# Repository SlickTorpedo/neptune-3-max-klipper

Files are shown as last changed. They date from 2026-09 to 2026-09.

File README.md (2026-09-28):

# neptune-3-max-klipper

> ### ⚠️ Read this first
>
> **Until this note is removed, most of the writing in this repo, including this README and the docs
> alongside it, is Claude's, not a record of a finished build.** It started as a plan drafted
> alongside the work.
>
> Since 2026-09-26, part of it has been **verified on the real machine**: the CAN bus, the toolhead
> board, the Eddy probe, homing, gantry levelling, heater tuning, the extruder and the start/end macros. Those parts are ticked below,
> and the measurements are in [`docs/can-bringup.md`](docs/can-bringup.md). Everything else is still
> plan. The first print is running as of 2026-09-27; nothing has been judged yet.
>
> If you found this repo looking to do the same conversion yourself: **don't follow it blindly yet.**
> Come back when this note is gone. That's the signal the build is done and the docs describe reality.

Gutting an Elegoo Neptune 3 Max and rebuilding it as a real printer: Klipper on a BTT Octopus v1.1,
an SB2209 CAN toolhead on a single umbilical, and a Stealthburner + CW2 carrying an X1C hotend,
probed by a BTT Eddy Duo running [eddy-ng](https://github.com/vvuk/eddy-ng).
The frame, the gantry and the 420 × 420 × 500 build volume stay. Almost nothing else does.

This repo is the config, the wiring notes, and the build log for that conversion.

> **Status (2026-09-27): first print running.** Electronics up, motion and probing calibrated.
> All three MCUs (Octopus, SB2209, Eddy Duo) are running Klipper. Z homes on the Eddy, `Z_TILT_ADJUST`
> levels the gantry to about 0.001 mm, and both heaters are PID-tuned.
> Done 2026-09-27: silicone spacers + tram (mesh 0.72 mm, gantry bow only), new Y motor, extruder verified
> (100 mm = 100 mm), PRINT_START / PRINT_END with KAMP, and an OrcaSlicer profile. **Next:** judge the first print, input shaping.

<p align="center">
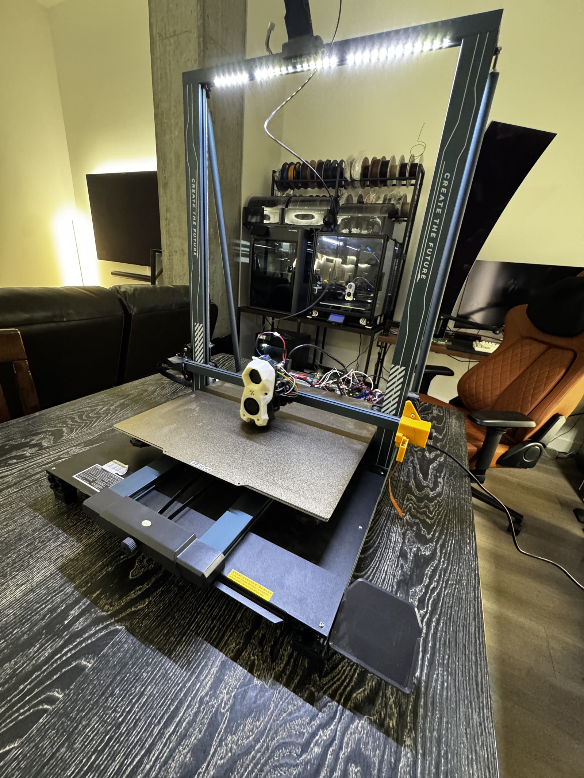
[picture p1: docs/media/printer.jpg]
The converted Neptune 3 Max
  
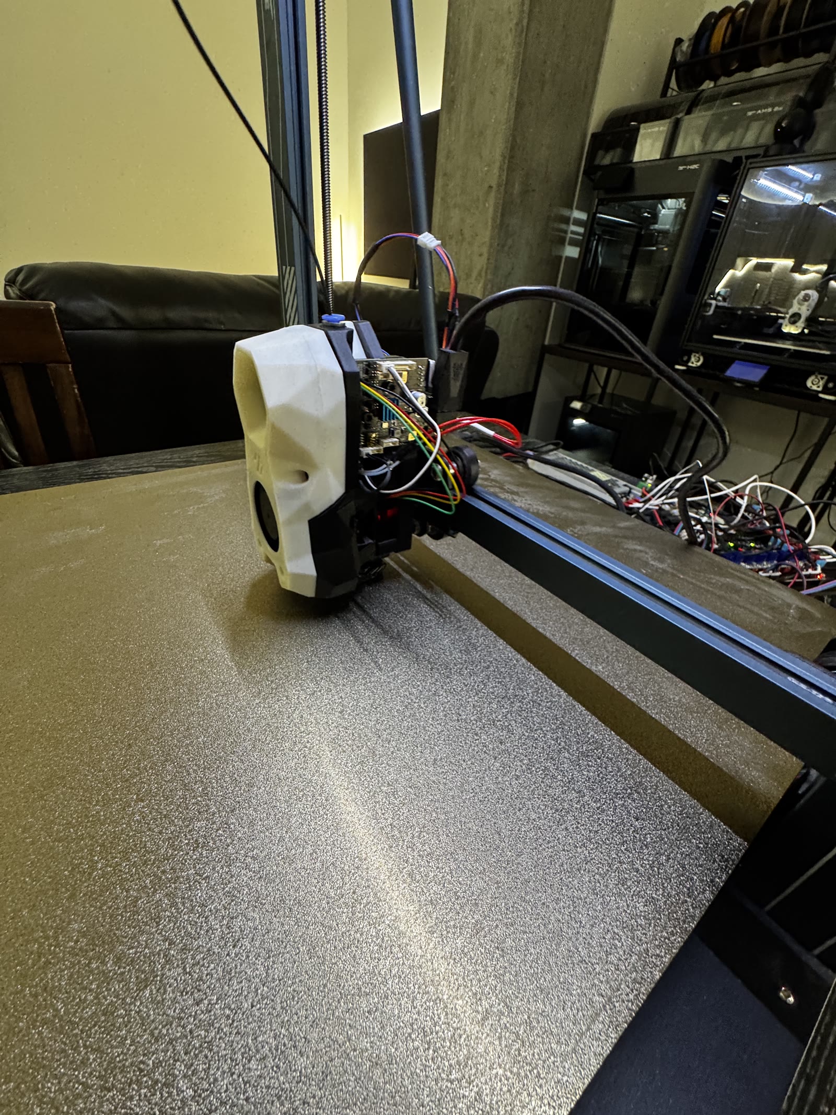
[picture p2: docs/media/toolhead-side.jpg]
Stealthburner toolhead with the SB2209 on the back
  
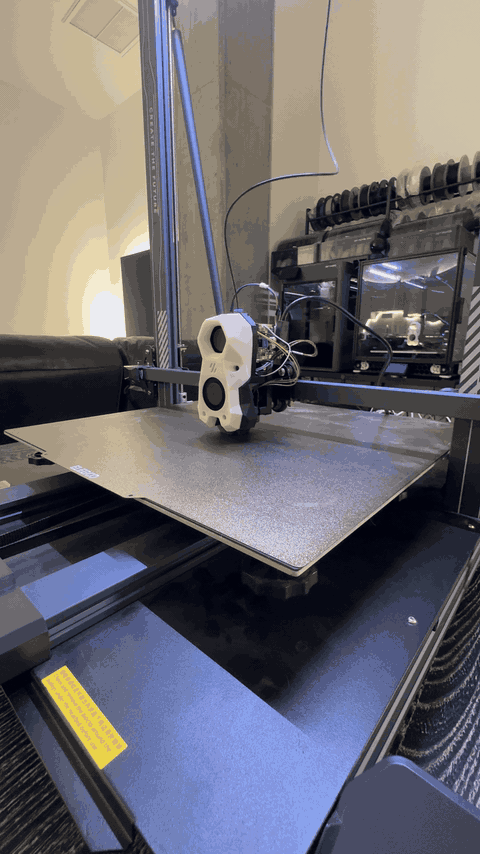
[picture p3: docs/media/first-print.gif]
First print (Voron cube), 2026-09-27
  
</p>

<p align="center"><sub>
  <b>Left:</b> the whole machine. <b>Middle:</b> Stealthburner + CW2 with the SB2209 on the back; the Eddy Duo is sealed inside.
  <b>Right:</b> first print, a Voron cube, 2026-09-27 (<a href="docs/media/first-print.mp4">MP4</a>).
</sub></p>

---

## Why

The Neptune 3 Max is a big printer sold at a small price, and every corner that got cut shows up
the moment you ask it for anything. The stock story:

- A closed-ish Marlin build on an Elegoo/MKS board with no meaningful tuning surface: no input
  shaping worth the name, no pressure advance you can iterate on, no real macro system.
- A PTFE-lined hotend that caps out around 260 °C and clogs if you look at it funny, on a
  proprietary extruder assembly.
- A 420 × 420 DC-powered bed that takes forever to come up to temperature and never gets flat.
- Stock ABL that samples too few points for a bed this size and fights a gantry that sags.
- Wiring that makes the toolhead a bird's nest of loose conductors dragging across the gantry.

The frame, the Z height and the sheer footprint are the parts worth keeping. Everything that
touches filament or decides where the nozzle goes gets replaced.

---

## The plan, in one table

| Subsystem | Stock | Target | State |
|---|---|---|---|
| Firmware | Marlin (Elegoo build) | **Klipper** + Moonraker + Mainsail | ✅ running |
| Host | — | **Raspberry Pi** | ✅ |
| Mainboard | Elegoo/MKS ZNP Robin Nano | **BTT Octopus v1.1** (STM32F446), plain USB Klipper | ✅ |
| Stepper drivers | Onboard, fixed | **TMC2209** UART | ✅ |
| Toolhead wiring | Loose harness to mainboard | **CAN bus**, single umbilical, 1 Mbit | ✅ |
| CAN adapter | — | **BTT U2C v2.1** | ✅ |
| Toolhead board | — | **BTT SB2209** (STM32G0B1), Katapult + Klipper | ✅ |
| Extruder | Elegoo direct drive | **Stealthburner + CW2** (Filamatrix) | fitted; direction/rotation not checked |
| Hotend | PTFE-lined, ~260 °C max | **X1C / Bambu-style** ceramic heater, Generic 3950 | ✅ PID-tuned |
| Probe | Elegoo ABL sensor | **BTT Eddy Duo** in CAN mode (its own node) + **eddy-ng** | ✅ calibrated, tap works |
| Z | Dual screws, belt-synced | **Independent dual Z** + `z_tilt` | ✅ |
| Bed leveling | Knobs + mesh | `z_tilt` + eddy-ng tap + Eddy rapid-scan adaptive mesh | ✅ mesh / 🔜 tram |
| Heated bed | Stock DC bed | Stock DC bed via an **external DC MOSFET** on Octopus HE0 | ✅ PID-tuned |
| Part cooling | Single stock blower | Stealthburner part fan + 4010 hotend fan | ✅ both verified |
| LEDs / feedback | Stock LCD | Stealthburner WS2812B LEDs | not fitted (config ready, commented out) |

---

## Bill of materials

`[x]` = in hand, `[ ]` = not sourced yet.

### Electronics
- [x] BTT Octopus v1.1 + TMC2209 drivers
- [x] BTT SB2209 CAN toolhead board
- [x] BTT U2C v2.1 USB-to-CAN adapter (arrived early, 2026-09-26)
- [x] Raspberry Pi host
- [x] Umbilical: the SB2209 kit cable (24 V, GND, CANH, CANL) to the U2C; the U2C's 24 V/GND terminals are fed from the PSU
- [x] Second Z motor for independent Z
- [x] 24 V PSU. Still worth **checking its rating against the new total load**.
- [x] DC MOSFET module for the bed, driven from Octopus HE0
- [x] Ferrules, heat-shrink, crimp tooling

The CAN bus runs from the U2C to the toolhead. It's terminated at exactly two points: the **U2C**
and the **Eddy Duo**, which has its own built-in terminator. The SB2209's 120R jumper is **off**:
with it on, the bus measured 41 Ω; with it off, 60 Ω. Bring-up steps, jumpers, UUIDs and every
measurement are in [`docs/can-bringup.md`](docs/can-bringup.md).

### Toolhead
- [x] Stealthburner shroud + CW2 kit (Filamatrix, single filament switch on the SB2209, verified)
- [x] X1C-style hotend
- [x] Part cooling blower + 4010 hotend fan
- [x] Stealthburner LED PCB / WS2812B (not fitted yet)
- [ ] Hotend→CW2 adapter mount (the same problem already solved on the Voron; reuse that solution)
- [x] **BTT Eddy Duo** scanning probe (CAN mode, sealed in the Stealthburner; flashed over CAN without opening it)

Still open for the X1C hotend: confirm the **ceramic heater's wattage against what the SB2209's
heater output can safely supply**. The thermistor is settled: `Generic 3950` reads correctly at
room temperature and PID-tuned cleanly at 250 °C.

### Electronics layout (temporary)

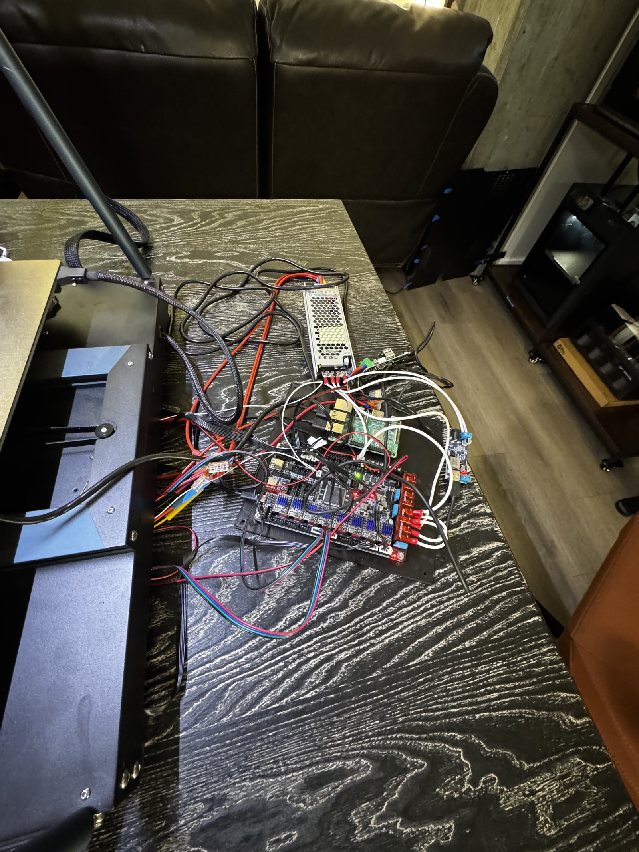
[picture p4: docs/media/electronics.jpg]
Bench layout of the electronics


For now the Octopus, Pi, U2C, PSU and the bed's DC MOSFET module sit loose next to the printer while things are still changing.
A proper holder that mounts them under the printer is planned once the layout settles.

<br clear="right">

### Mechanical
- [x] **Carriage adapter.** Ben Ford's Neptune 3/4 Stealthburner plate (Printables 1185615), fitted.
      The Eddy coil sits 27.33 mm behind the nozzle, and the bottom of its case is about 2.0 mm
      above the nozzle tip.
- [x] Hardware to de-sync the Z screws and mount the second motor
- [x] Belts / tensioners
- [x] Umbilical anchor points
- [x] 18 mm silicone bed spacers (4 mm ID) to replace the bed springs; 7 needed (M3 screws)

---

## Repo layout

```
config/            Klipper configs (the Pi's ~/printer_data/config mirrors this)
  printer.cfg        Root config: Octopus, steppers, bed heater, and the SAVE_CONFIG block
  hardware/
    sb2209.cfg       Toolhead MCU, extruder, hotend, fans, ADXL, Filamatrix sensor
    eddy.cfg         Eddy Duo MCU + probe_eddy_ng
    eddy_homing.cfg  homing_override: Z always homes with the coil over the bed centre
    z_tilt.cfg       Dual-Z levelling (stepper_z is the RIGHT screw)
    screws_tilt.cfg  Bed tramming over the 6 outer bed screws
    bed_mesh.cfg     21×21 mesh, scanned at 2 mm
  macros/print.cfg   PRINT_START / PRINT_END (eddy-ng tap + native adaptive mesh + KAMP purge)
  KAMP_Settings.cfg  KAMP (LINE_PURGE, SMART_PARK). On the Pi, config/KAMP is a symlink to
                     ~/Klipper-Adaptive-Meshing-Purging/Configuration, and mainsail.cfg comes from mainsail-config
docs/
  can-bringup.md     The bring-up log: hardware IDs, jumpers, UUIDs, every calibration result
firmware/          Katapult/Klipper .config per MCU (Octopus, SB2209, Eddy Duo) + where each value came from
stl/               Printable parts, sorted by print colour
  toolhead/          Stealthburner + CW2 (FilamATrix) for the X1C hotend
cad/               Adapter plates and printed brackets specific to this conversion
```

`stl/` is organised so each colour folder can be imported whole and printed in one go. See
[`stl/toolhead/README.md`](stl/toolhead/README.md) for the layout and the variant choices.

**Keeping the Pi and the repo in sync:** `SAVE_CONFIG` writes calibration into `printer.cfg` on
the Pi. Copy it back into `config/` after every save.

---

## Build phases

### Phase 0: Document the stock machine *(before the screwdriver comes out)*
- [ ] Photograph the wiring harness end to end, both ends of every connector
- [ ] Record stock steps/mm, belt pitch, pulley tooth counts, lead-screw pitch
- [ ] Note thermistor types and heater wattage (bed especially, since it gets reused)
- [ ] Record endstop types and wiring polarity (NO/NC)
- [ ] Back up the stock firmware and anything worth remembering from its settings

### Phase 1: Teardown
- [x] Strip the stock toolhead, mainboard, display and harness
- [x] Keep: frame, gantry, rails, motors, bed, PSU
- [x] De-sync the Z screws and fit the second Z motor
- [ ] Inspect rails and lead screws; clean and re-lube

### Phase 2: Electronics bring-up
- [x] U2C on `can0` at 1 Mbit (fixed U2C firmware flashed); Octopus on plain USB Klipper
- [x] Katapult on the SB2209 via USB DFU, then Klipper over CAN; Eddy Duo flashed over CAN through its factory bootloader
- [x] Termination at both ends of the bus and nowhere else (60 Ω)
- [x] Both Z motors move together and in the same direction (positive = up)
- [ ] Extruder direction under a cold/hot extrude test

### Phase 3: Mechanical install
- [x] Mount the Octopus and the Pi, route the umbilical
- [x] Fit the carriage adapter + Stealthburner + X1C hotend
- [ ] Re-tension belts, square the gantry
- [ ] Swap bed springs for silicone spacers, then tram with `SCREWS_TILT_CALCULATE`

### Phase 4: First motion
- [x] X/Y homing on the stock switches
- [x] Z homes on the Eddy (`probe:z_virtual_endstop`, eddy-ng)
- [x] `z_tilt` defined for the real screw positions; `Z_TILT_ADJUST` converges to about 0.001 mm.
      The first attempt diverged because the bench config had the Z motors labelled backwards.
- [x] Probe offsets measured (x 0, y +27.33); Z offset comes from the eddy-ng tap before each print
- [ ] Sanity-check `position_max` for the full 420 × 420 × 500 envelope

### Phase 5: Heat and tune
- [x] PID: hotend (250 °C) and bed (60 °C)
- [x] eddy-ng setup, warm; tap standard deviation 0.001 mm
- [x] Mesh baseline: 21×21 rapid scan, range 0.91 mm (about 0.24 mm gantry bow plus a bed twist, to be trammed out)
- [ ] `verify_heater` / thermal runaway verified by actually provoking it
- [ ] `rotation_distance` calibration for E (XY too)
- [ ] Input shaping (ADXL on the SB2209, responding), pressure advance, flow

### Phase 6: Make it pleasant
- [ ] PRINT_START / PRINT_END: home, heat, Z_TILT, clean nozzle at 150 °C, tap, adaptive mesh, purge
- [ ] Filament runout handling (Filamatrix), pause/resume that doesn't compound errors
- [ ] Stealthburner LEDs (optional)
- [ ] Timelapse, camera, remote monitoring

---

## Open decisions

1. **Bed.** Now the stock DC bed through an external MOSFET. AC bed + SSR is still a real upgrade
   and a real safety project. Deferred, not dismissed.
2. **PSU headroom.** Add up the new load (bed + hotend + steppers + fans + Pi) against the
   supply's rating.
3. **Gantry.** It visibly bows in the middle (about 0.24 mm on the Eddy). The mesh compensates for
   now; the gantry is due to be replaced eventually.
4. **Stock Elegoo runout sensor.** Still wired (Octopus PG10) but not mounted. It pauses nothing and
   isn't used by any macro.
5. **Eddy height.** eddy-ng's ideal is about 1.75 mm from the case bottom to the nozzle tip; this
   mount gives about 2.0. Tap works well as is, so only revisit it if taps get unreliable.

## Known quirks

- **"Failed automated reset of MCU 'eddy'"** after a config change: the Eddy (software CAN on its
  RP2040) sometimes misses Klipper's reset command. Run `FIRMWARE_RESTART` again; it has worked every time.
- **The Pi sometimes comes back as `neptune-2.local`** (mDNS name clash). It returns to
  `neptune.local` on its own later.
- **eddy-ng patches Klipper's source.** Before updating Klipper: `~/eddy-ng/install.sh --uninstall`,
  update, reinstall, then rebuild and reflash the MCUs. See [`firmware/README.md`](firmware/README.md).

---

## Safety

Blunt, because this build touches heaters and possibly mains:

- **Verify the X1C heater's power draw against the SB2209's heater output.** An undersized MOSFET
  on an oversized heater is a fire, not a fault.
- **Mains wiring is not a "figure it out as you go" area.** Earth to every metal case, proper
  connectors, strain relief. If the AC bed happens, it also gets a grounded bed plate, a correctly
  rated SSR with a heatsink, and a thermal fuse.
- **Thermal runaway protection gets tested, not assumed.** Klipper's `verify_heater` only helps
  if the config is right and you've watched it trip.
- **The hotend fan has no speed sensor.** It was once found jammed mid-heat. A stalled hotend fan
  cooks the Stealthburner's printed parts, so look at it after any toolhead work.
- **Never leave the first heat soak unattended.**
- No unattended printing until PID, runaway protection and the first hundred hours are behind it.

---

## References

- Klipper: https://www.klipper3d.org/
- Klipper CAN bus guide: https://www.klipper3d.org/CANBUS.html
- Esoterical's CANBus guide: https://canbus.esoterical.online/
- Moonraker: https://moonraker.readthedocs.io/
- Mainsail: https://docs.mainsail.xyz/
- BTT Octopus v1.1 docs: https://github.com/bigtreetech/BIGTREETECH-OCTOPUS
- BTT SB2209 docs: https://github.com/bigtreetech/EBB
- BTT Eddy: https://github.com/bigtreetech/Eddy
- eddy-ng: https://github.com/vvuk/eddy-ng (wiki: https://github.com/vvuk/eddy-ng/wiki)
- Katapult (CAN bootloader): https://github.com/Arksine/katapult
- Voron Stealthburner: https://github.com/VoronDesign/Voron-Stealthburner
- Neptune 3 Max bed screw positions: https://github.com/TheFeralEngineer/Klipper-for-Elegoo-Neptune-series-3D-Printers

---

## License

TBD.

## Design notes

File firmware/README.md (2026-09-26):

# Firmware build configs

One `.config` per board and per image. Build on the Pi with:

```bash
cd ~/klipper   # or ~/katapult
make clean KCONFIG_CONFIG=<path>/klipper_sb2209.config
make KCONFIG_CONFIG=<path>/klipper_sb2209.config
```

The files were generated with `make olddefconfig` against Klipper `ce7002b` (2026-09-18) and Katapult
`ec59b9b` (2026-03-20). If the Pi's checkouts are newer, run `make menuconfig KCONFIG_CONFIG=...`
once and check that the values below still hold before building.

The CAN adapter is a **BTT U2C v2.1**, so the Octopus is **not** a USB-to-CAN bridge.

| File | Board | Key values | Source |
|---|---|---|---|
| `klipper_octopus_usb.config` | Octopus v1.1, STM32F446ZET6 (chip read off the board 2026-09-25) | 32KiB bootloader, 12 MHz crystal (crystal can reads 12.000), USB on PA11/PA12 | Esoterical guide, Octopus page, F446 screenshots. The bridge config there differs only in the communication interface. |
| `katapult_sb2209.config` | EBB SB2209 CAN v1.0, STM32G0B1 | 8KiB deployer + 8KiB app offset, 8 MHz crystal, CAN on PB0/PB1, 1,000,000, double-reset entry, status LED PA13 | Esoterical guide, "BigTreeTech SB2209 and SB2240" page, Katapult screenshot |
| `klipper_sb2209.config` | same | 8KiB bootloader, 8 MHz crystal, CAN on PB0/PB1, 1,000,000 | same page, Klipper screenshot. 8 MHz crystal (X1) and FDCAN2 on PB0/PB1 are also confirmed in BTT's `BIGTREETECH EBB SB2209 CAN V1.0_SCH.pdf`. |
| `katapult_eddy.config` | Eddy Duo, RP2040 | W25Q080 CLKDIV 2, 16KiB bootloader, CAN RX gpio4 / TX gpio5, 1,000,000, no status LED | Esoterical guide, "BigTreeTech Eddy Duo" page, Katapult screenshot. **Only needed for a USB recovery.** The plan is to use whatever bootloader the Eddy already has. |
| `klipper_eddy.config` | same | 16KiB bootloader, CAN RX gpio4 / TX gpio5, 1,000,000 | same page, Klipper screenshot |

Notes:

- **eddy-ng:** the Pi's `~/klipper` has eddy-ng (1ed056b) installed. That links `src/sensor_ldc1612_ng.c` and
  two klippy extras, and patches `src/Makefile` and `klippy/extras/bed_mesh.py`. The Eddy image **must** be
  built from that patched tree. The SB2209 image was rebuilt from it too. The Octopus keeps its existing firmware: same Klipper commit, and only the Eddy uses the new sensor code.
  Before any Klipper update: `~/eddy-ng/install.sh --uninstall`, `git pull`, `install.sh`, then rebuild and
  reflash all MCUs.

- **Eddy offset:** on the RP2040, Katapult always launches the application at `0x10004000` (fixed in
  `katapult/src/rp2040/Kconfig`, `LAUNCH_APP_ADDRESS`). So any Katapult/CanBoot the Eddy shipped
  with requires the 16KiB bootloader offset, and there's nothing to guess.
- **Eddy I2C bus:** BTT's sample config uses `i2c0f` (i2c0 on GPIO20/21), which doesn't clash with
  the CAN pins (GPIO4/5).
- **CAN bitrate:** every image uses 1,000,000, matching `can0` on the Pi.

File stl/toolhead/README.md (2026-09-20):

# Toolhead STLs

Stealthburner + Clockwork 2 (FilamATrix fork) with a Bambu/X1C-style hotend, sorted by
**print color** rather than by upstream source.

Each colour folder is meant to be imported whole: select the entire folder, drop it on the
plate, set one colour, print. No file-by-file picking, no leftover parts you didn't want.

## Folders

| Folder | Print in | What's in it |
|---|---|---|
| `primary/` | Primary colour | Main structural parts with no filename prefix |
| `accent/` | Accent colour | Everything upstream marked `[a]` |
| `clear/` | Clear / translucent | The LED diffuser — it has to pass light |
| `opaque/` | Opaque, ideally black | LED carrier and diffuser mask — these **block** light; a translucent print here bleeds and ruins the effect |
| `jigs/` | Anything | Assembly tools, not printer parts. Print once, keep in the toolbox |
| `alternates/` | **Don't print** | The roads not taken — see below |

## Quantities

**Every part here is quantity 1.** Nothing needs duplicating.

Voron's own file convention encodes quantity in the filename with an `_x2` / `_x3` / `_x4`
suffix — a part needed in multiples ships pre-named that way. None of the files in this set
carry a suffix, upstream or here, so a single copy of each is correct. If a part ever does
need multiples, it'll show up here as `name_x1.stl`, `name_x2.stl`, `name_x3.stl` so the
whole folder can still be imported in one go.

Filenames are otherwise unchanged from upstream, so they stay traceable to the source repos.

## What's in `alternates/` and why

These are the choose-one variants that lost. They're kept for reference in case a decision
gets revisited — **they are not part of the build as specified.**

| File | Why it's not being printed |
|---|---|
| `main_body_clockwork2_no_switch.stl` | AFC default (relies on buffer ramming instead of a toolhead sensor) |
| `main_body_clockwork2_dual_switch.stl` | Two switches; only one is needed here |
| `cable_cover_pcb.stl` | Pairs with the no-switch body |
| `[a]_knife_holder_olfa.stl` | Olfa blade variant; this build uses a standard razor |
| `razor_safety_cap_olfa.stl` | Same — Olfa variant |
| `chain_anchor_2hole.stl` / `chain_anchor_3hole.stl` | For cable chains. This build runs a CAN umbilical, so there's no chain to anchor |

**Chosen configuration:** single-switch CW2 main body + `cable_cover_pcb_w_sensor`, standard
razor blade, Filametrix cutter included, no cable chain.

## Print settings

Standard Voron guidance applies:

- **ABS or ASA.** These parts sit next to a hotend; PLA will sag and deform.
- 4 perimeters, 5 top/bottom layers, 40% infill
- No supports needed on any part — they're all oriented to print as-is
- The `clear/` diffuser wants a translucent filament; SLA prints of this part are common and
  look better than FDM if that's an option

## Sources

- FilamATrix (CW2 fork with the toolhead cutter) — https://github.com/thunderkeys/FilamATrix
- Voron Stealthburner (stock Stealthburner + CW2 parts) — https://github.com/VoronDesign/Voron-Stealthburner

The upstream READMEs that came with the download are preserved verbatim in `reference/`.

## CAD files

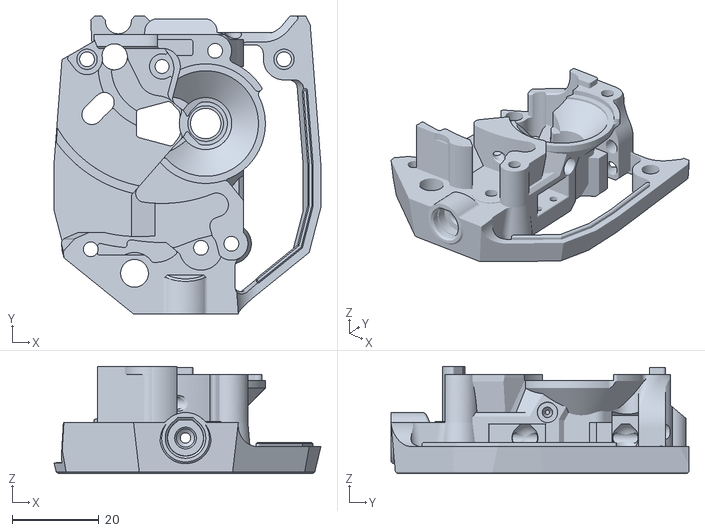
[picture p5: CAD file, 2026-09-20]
stl/toolhead/alternates/main_body_clockwork2_dual_switch.stl
61.5 x 68.7 x 24.7

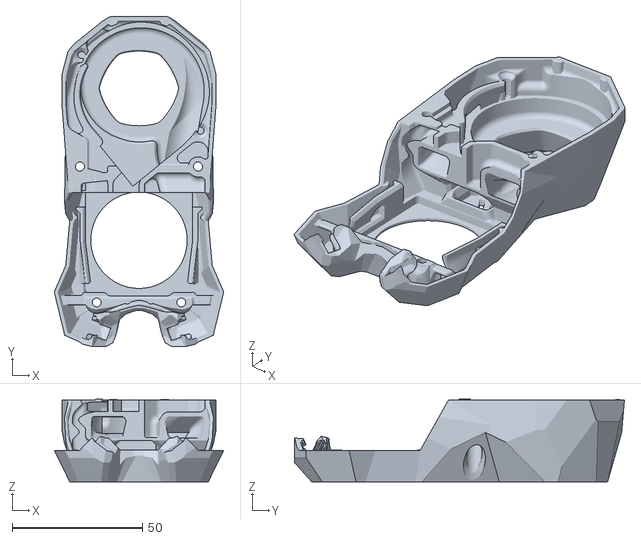
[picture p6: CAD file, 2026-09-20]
stl/toolhead/accent/[a]_stealthburner_main_body.stl
65.1 x 126.8 x 31.8

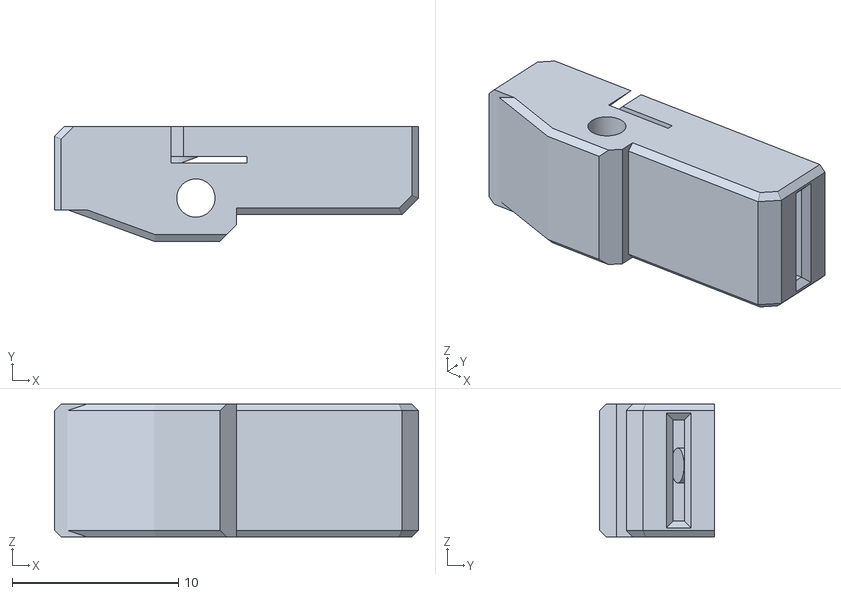
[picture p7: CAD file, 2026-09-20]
stl/toolhead/accent/[a]_knife_holder.stl
21.9 x 6.90 x 8.00

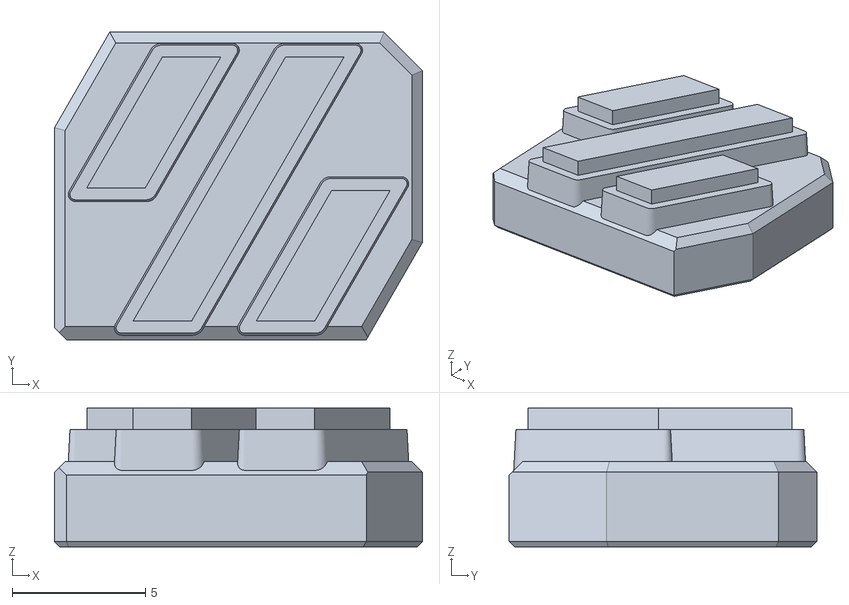
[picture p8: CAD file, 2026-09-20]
stl/toolhead/clear/[c]_stealthburner_LED_diffuser.stl
13.8 x 11.5 x 5.20

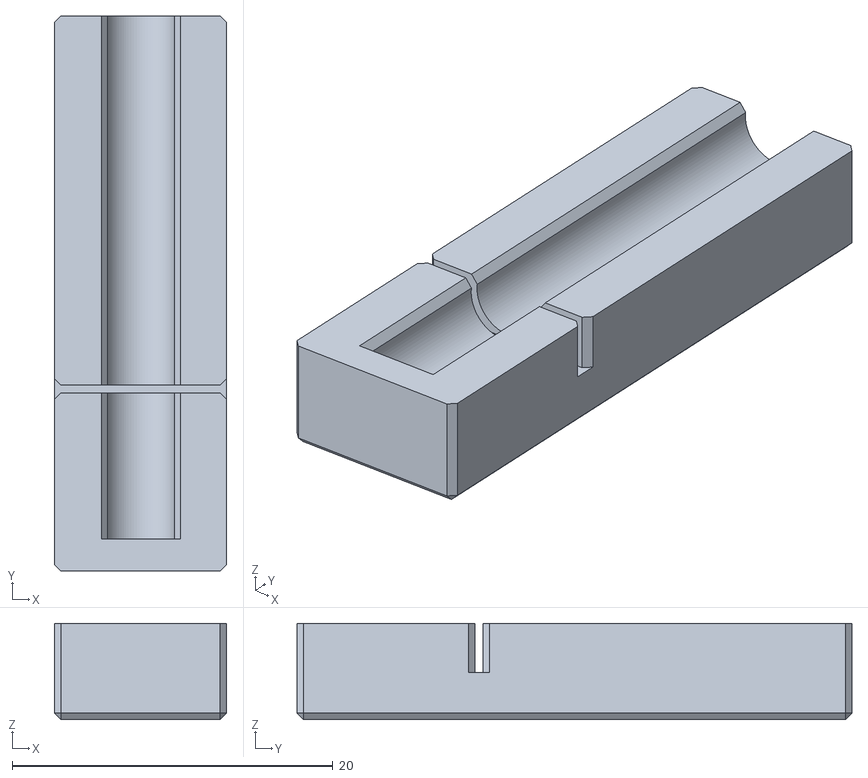
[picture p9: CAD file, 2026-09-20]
stl/toolhead/jigs/bambu_ptfe_jig.stl
10.7 x 34.6 x 6.00

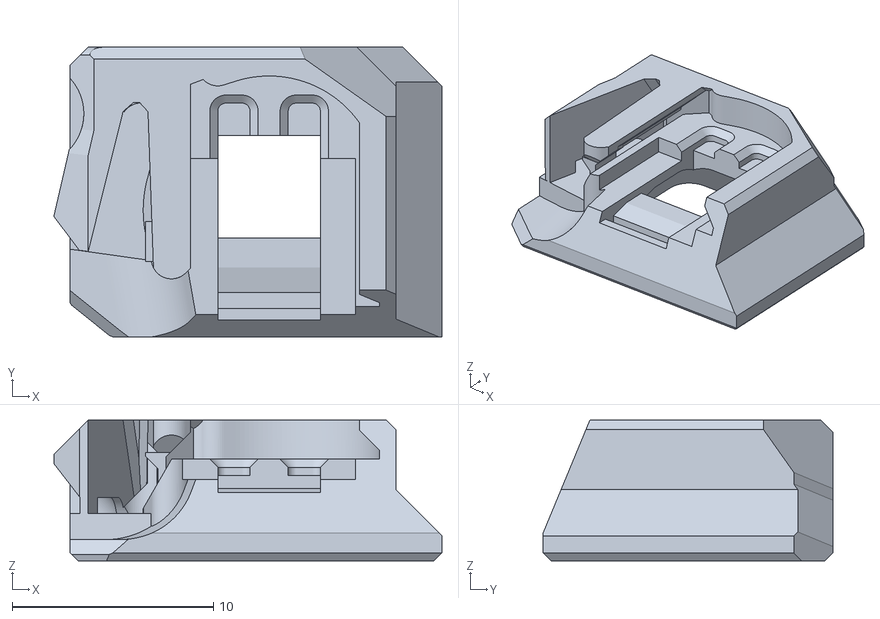
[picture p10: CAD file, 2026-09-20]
stl/toolhead/opaque/[o]_stealthburner_LED_carrier.stl
19.3 x 14.4 x 7.01

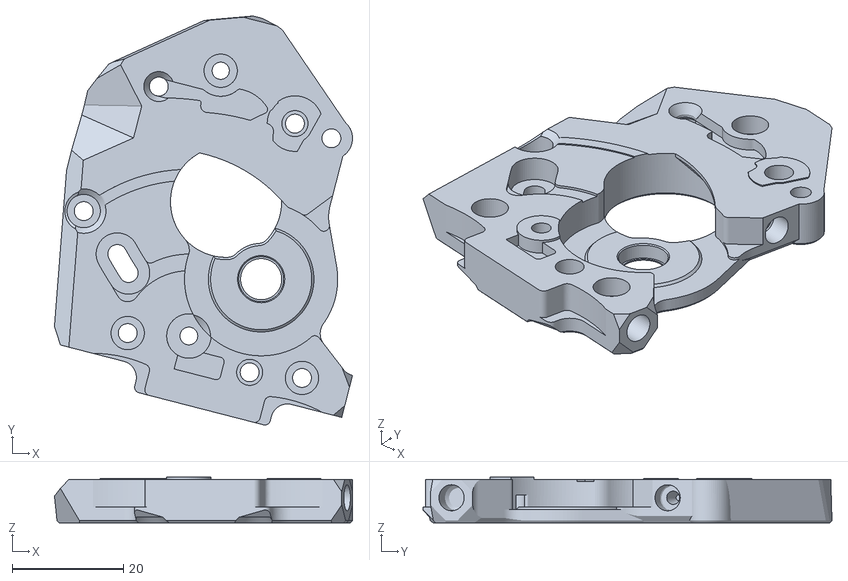
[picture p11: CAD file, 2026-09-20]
stl/toolhead/primary/motor_plate.stl
53.7 x 73.6 x 8.20

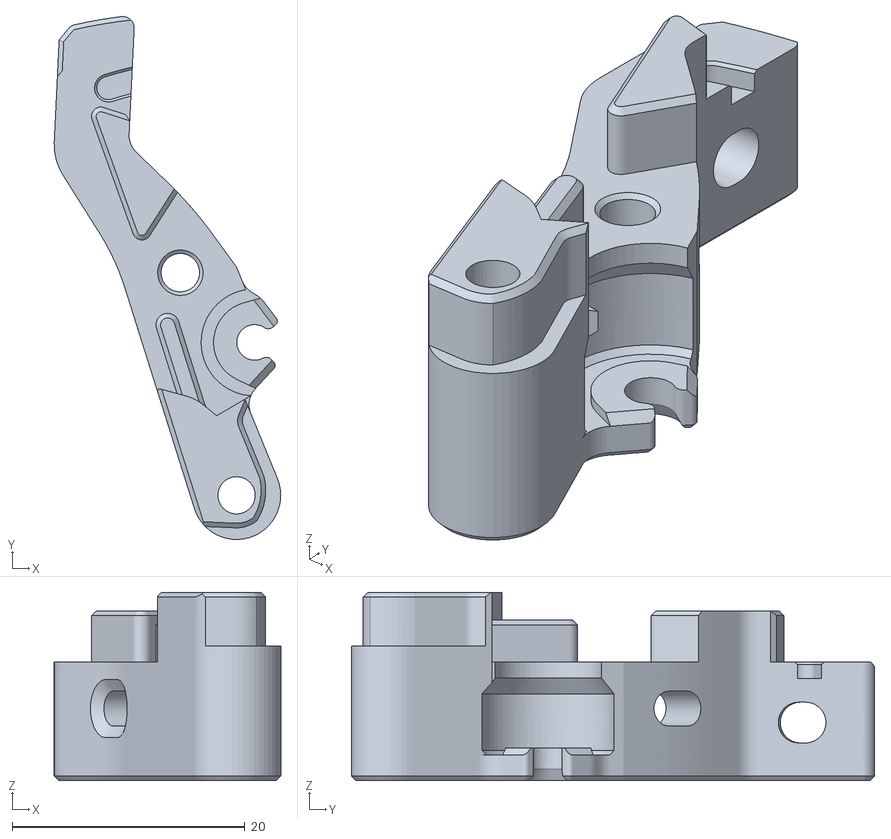
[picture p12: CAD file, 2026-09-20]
stl/toolhead/accent/[a]_guidler_a.stl
19.5 x 45.0 x 16.2

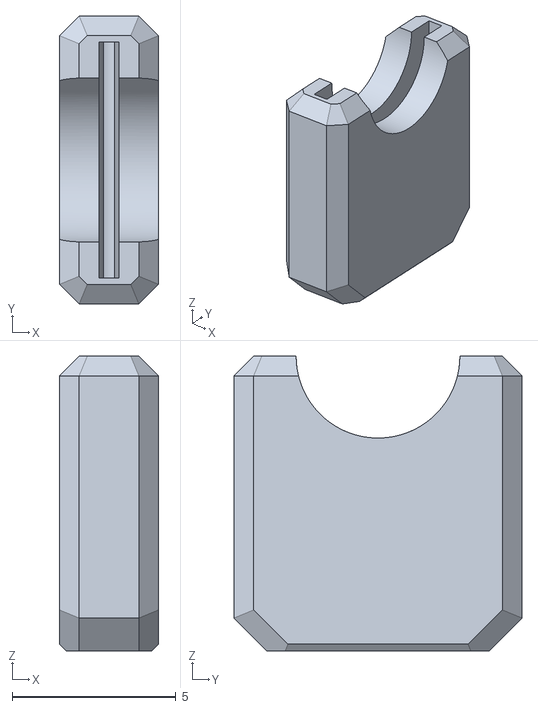
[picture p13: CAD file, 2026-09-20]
stl/toolhead/jigs/razor_safety_cap.stl
3.02 x 8.80 x 9.00

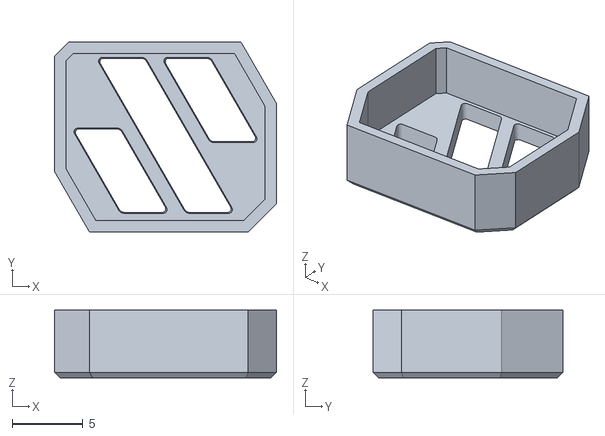
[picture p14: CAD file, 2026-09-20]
stl/toolhead/opaque/[o]_stealthburner_LED_diffuser_mask.stl
15.7 x 13.4 x 4.80

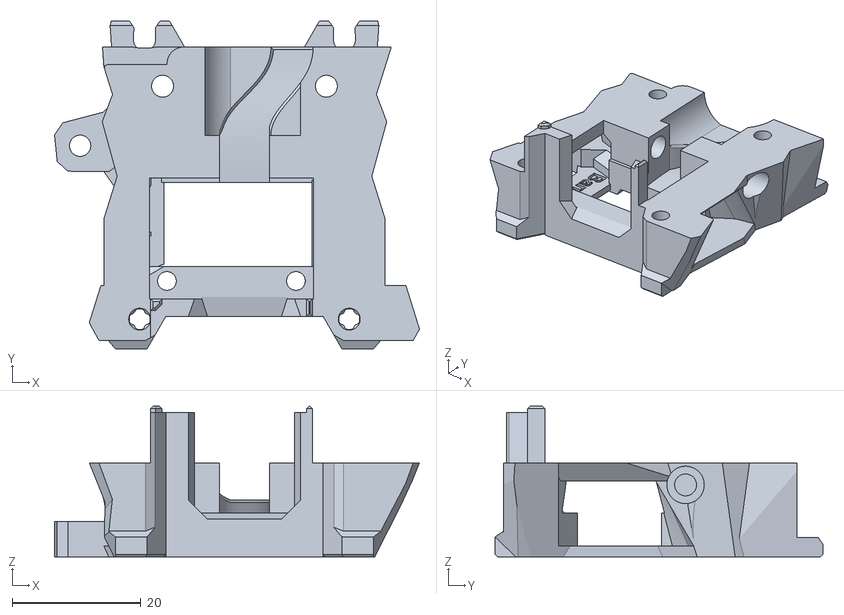
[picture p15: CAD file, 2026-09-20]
stl/toolhead/primary/bambu_rear.stl
56.6 x 50.8 x 23.4

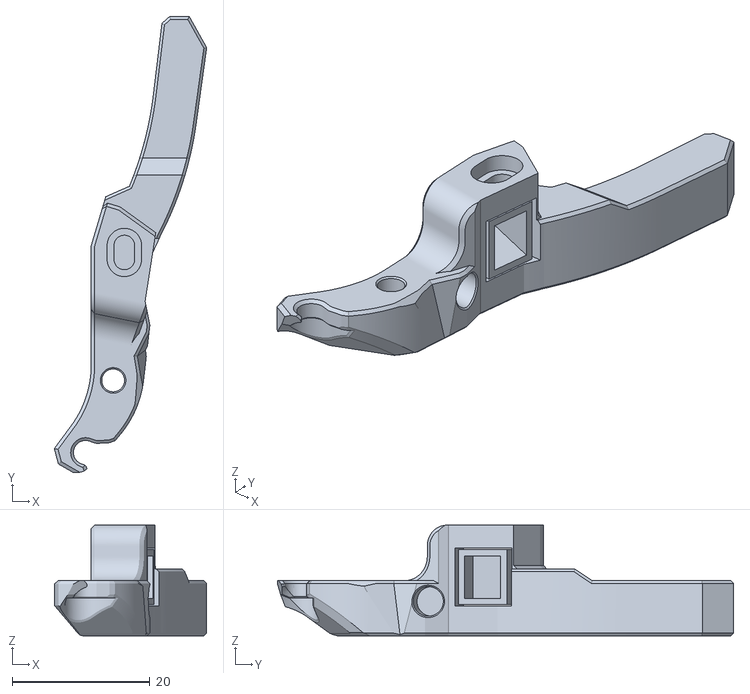
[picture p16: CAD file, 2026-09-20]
stl/toolhead/accent/[a]_cutting_arm_clockwork2.stl
22.1 x 66.1 x 16.0

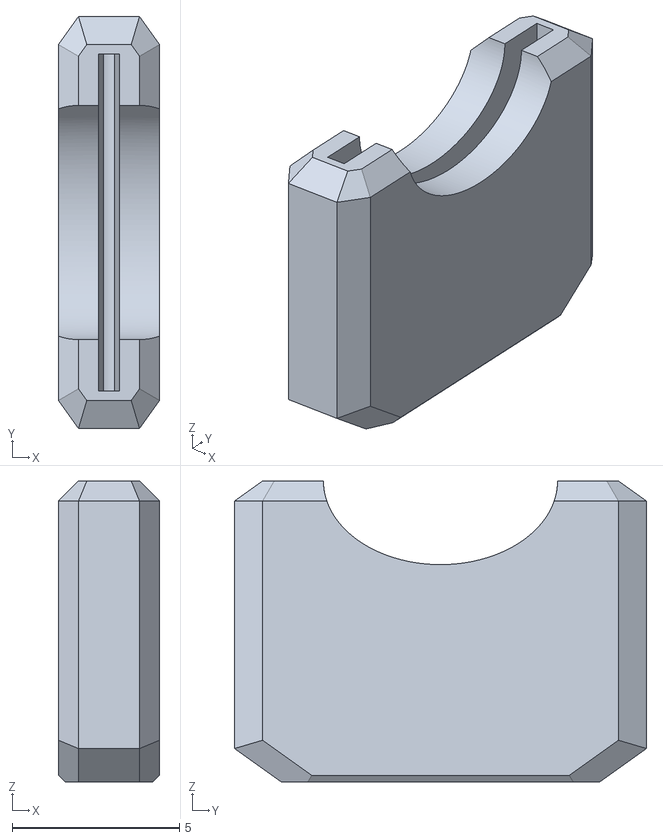
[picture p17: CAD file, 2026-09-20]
stl/toolhead/alternates/razor_safety_cap_olfa.stl
3.02 x 12.3 x 9.00

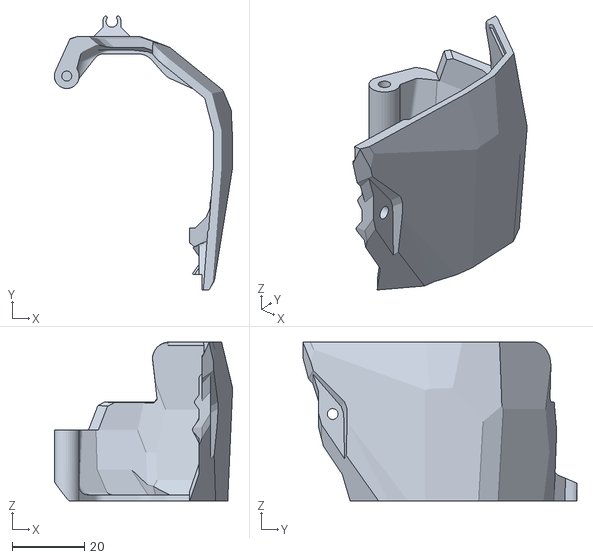
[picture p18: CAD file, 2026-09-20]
stl/toolhead/primary/cable_cover_pcb_w_sensor.stl
49.5 x 76.0 x 44.1

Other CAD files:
stl/toolhead/primary/main_body_clockwork2_single_switch.stl
stl/toolhead/alternates/main_body_clockwork2_no_switch.stl
stl/toolhead/alternates/[a]_knife_holder_olfa.stl
stl/toolhead/accent/[a]_guidler_b.stl
stl/toolhead/accent/[a]_latch_ecas.stl
stl/toolhead/accent/[a]_latch_shuttle.stl
stl/toolhead/accent/[a]_pcb_spacer.stl
stl/toolhead/alternates/cable_cover_pcb.stl
stl/toolhead/alternates/chain_anchor_2hole.stl
stl/toolhead/alternates/chain_anchor_3hole.stl
stl/toolhead/primary/bambu_front.stl

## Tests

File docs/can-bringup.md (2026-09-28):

# CAN bring-up: U2C, SB2209 and Eddy Duo

Status: **bus up, all three MCUs ready in Klipper (2026-09-26)**; next is calibration (started 2026-09-25). Nothing on this page has been powered up yet unless a
step is ticked.

## Hardware as identified

| Part | Detail | How it was confirmed |
|---|---|---|
| Host | Raspberry Pi, `neptune.local`, user `pi`, Klipper already installed | user |
| Mainboard | BTT Octopus v1.1, **STM32F446ZET6**, 12 MHz crystal. Already runs USB Klipper (`usb-Klipper_stm32f446xx_330034000951343437373238-if00` in the bench config). | photo of the chip |
| CAN adapter | **BTT U2C v2.1** (arrives 2026-09-27). Replaces the planned Octopus USB-to-CAN bridge. | user decision |
| Toolhead board | BTT EBB SB2209 CAN v1.0, **STM32G0B1** | user read the chip |
| Probe | BTT Eddy Duo, switch set to **CAN**, own RP2040 node | user |
| Eddy connection | 4-pin CAN BUS port (5V / CAN-H / CAN-L / GND) on the SB2209's fan board (SB0000). That board gets CAN_P/CAN_N and 5V through the SB2209's 2×7 header (J1/J2), so the Eddy is a short stub on the same bus, powered by the SB2209's 5V 1.5A buck. | BTT SB2209 V1.0 schematic |

## Bus topology and termination

```
Pi ──USB-C── U2C [120R ON] ══ umbilical (24V, GND, CAN-H, CAN-L) ══ SB2209 [120R OFF] ── fan board ── Eddy Duo [own 120R, fixed/sealed]
                   ▲ 24V/GND screw terminals ← PSU V+/V− (pass-through only)
Pi ──USB── Octopus (plain USB Klipper; its RJ12 CAN port is unused)
```

- The bus is terminated at the U2C and at the SB2209. The Eddy stub is only a few cm long, so at
  1 Mbit it counts as the same end as the SB2209.
- **Check with power off:** measure between CAN-H and CAN-L. **~60 Ω** is correct. ~40 Ω means a
  third terminator is active somewhere (most likely on the Eddy), so find it and turn it off.
  ~120 Ω means one end is missing its jumper.
- The Octopus's permanent 120 Ω resistor isn't on this bus, because nothing plugs into its RJ12.

## SB2209 jumpers

| Jumper | Setting | Why |
|---|---|---|
| V_FAN1, V_FAN2 | **VIN** (bottom row, jumper horizontal) | fans are 24 V (**check the fan labels**). Each row connects that voltage to V_FAN. A vertical jumper would short two supply voltages together. |
| V_4W FAN | none | 4-pin fan port unused |
| V_Proximity, NPN | none | no inductive probe |
| 2.2K (JP2, "PT1000") | **none** | puts 4.12k in parallel with 4.7k (= 2.2k) as the TH0 pull-up, which is only for a PT1000. The hotend uses Generic 3950. |
| 120R | **OFF** | With it on, CAN-H↔CAN-L read 41 Ω: the Eddy Duo has its own terminator switched on. The Eddy is physically the last node, so it terminates that end. With this jumper off: 60 Ω (2026-09-26). |
| USB_5V | **ON only while flashing over USB**, and never with 24V connected | powers the board from USB for DFU |

## Runbook

### A. Host prep (Pi on; toolhead disconnected)
- [x] SSH key access for Claude (`ssh neptune`); narrow NOPASSWD sudoers rule in `/etc/sudoers.d/010-klipper-flash` (dfu-util, systemctl klipper, dmesg, ip)
- [x] `git clone https://github.com/Arksine/katapult ~/katapult` (ec59b9b)
- [x] (already in place on 2026-09-25, matched the guide exactly) `can0` via systemd-networkd, following the current Esoterical "Getting Started" page. The old
      ifupdown `interfaces.d/can0` method has been retired there.
  - enable, start (unmask first if needed) `systemd-networkd`; disable `systemd-networkd-wait-online`
  - `/etc/udev/rules.d/10-can.rules`: `SUBSYSTEM=="net", ACTION=="change|add", KERNEL=="can*"  ATTR{tx_queue_len}="128"`
  - `/etc/systemd/network/25-can.network`: `[Match] Name=can*` / `[CAN] BitRate=1M` / `[Link] RequiredForOnline=no`
  - reboot
- [x] Pi Klipper is `77d5d942e` (2026-05-04). All new images are built from this same checkout, so the Octopus needs no reflash. Built images are in `~/fw-out/` on the Pi.

### B. SB2209 over USB (umbilical **disconnected**)
- [x] USB_5V jumper on, USB-C from Pi to SB2209. **The first cable failed to enumerate** (`device descriptor read/64, error -32` on two ports); a different cable worked.
- [x] Hold BOOT and RESET, release RESET, release BOOT. `lsusb` shows `0483:df11` (DFU serial 204F37854130)
- [x] 2026-09-25: flashed the `katapult_sb2209` build (4564 bytes, mass-erase, OK; the trailing `get_status` error is expected): `sudo dfu-util -R -a 0 -s 0x08000000:mass-erase:force:leave -D ~/katapult/out/katapult.bin -d 0483:df11` (from Esoterical toolhead_flashing)
- [ ] Remove USB, **remove USB_5V jumper**

### C. U2C and umbilical (from 2026-09-27)
- [x] 2026-09-26: U2C flashed with Esoterical's fixed `G0B1_U2C_V2.bin` (sha256 6c5c462b…0ff, matches the guide repo). It was running stock `budgetcan`, and `dfu-util -e -d 1d50:606f` put it into DFU without the BOOT button. Replugged: `1d50:606f`, `can0` UP at 1000000, qlen 128, `gs_usb` loaded.
- [ ] U2C 120R jumper on; U2C 24V/GND terminals to PSU V+/V−
- [ ] Umbilical plugged into the U2C and the SB2209
- [ ] **Power off:** ~60 Ω CAN-H↔CAN-L; no continuity from 24V to either CAN line
- [ ] Power on: `ip -details link show can0` shows UP and bitrate 1000000
- [ ] `sudo systemctl stop klipper`, then `~/katapult/scripts/flashtool.py -i can0 -q`
- [ ] Flash Klipper to the SB2209 through Katapult
- [ ] Eddy: listed as Katapult/CanBoot? If yes, flash `klipper_eddy`. If no, **stop** and go over the options.

## eddy-ng (installed 2026-09-25)

The user chose [eddy-ng](https://github.com/vvuk/eddy-ng) over BTT's stock Eddy flow. It replaces BTT's hot
temperature-compensation calibration with a cold `PROBE_EDDY_NG_SETUP` plus a nozzle "tap" before each print.
It's installed on the Pi, and `~/fw-out/klipper_eddy.bin` (52696 bytes) includes it. The eddy-ng docs say
tap works best with the **bottom of the Eddy's coil PCB about 2.95 mm above the nozzle tip** (about 1.75 mm
from the case bottom to the tip). Homing and meshing work at other heights; tap is the sensitive part.

## UUIDs

| Node | UUID | Application seen |
|---|---|---|
| SB2209 | `e0ee669c3821` | Katapult (ours, app 0x8002000) → Klipper, flashed 2026-09-26 |
| Eddy Duo | `6e4e53261cb4` | BTT factory Katapult/CanBoot (protocol 1.0.0, app 0x10004000) → Klipper + eddy-ng, flashed 2026-09-26, verified SHA 756A370B… |

## First power-on (2026-09-26)

- `can0` UP at 1M. First query: both nodes in Katapult. Identified with `flashtool.py -s`: stm32g0b1 = SB2209, rp2040 = Eddy.
  flashtool refuses to flash an image whose MCU type doesn't match, which is a useful safety net.
- The Pi came back as `neptune-2.local` (mDNS name clash). Connect with `ssh -o HostName=neptune-2.local -o HostKeyAlias=neptune.local neptune`.
- Klipper ready. Readings at room temperature: extruder 26.6 °C (bed 26.7 °C), SB2209 board 31 °C, Eddy NTC 36 °C, Eddy MCU 41 °C.
  ADXL (x, y, z) = (-919, -444, 9697), with gravity on Z. `PROBE_EDDY_NG_STATUS`: about 3.198 MHz, status 0x48 UNREADCONV1 DRDY (healthy, not calibrated).
- CAN stats: SB2209 rx_error 44, flat since startup; Eddy tx_retries about 23, flat.
- eddy-ng needs a non-zero probe offset and a `[bed_mesh]` section. Both are **placeholders** for now (x 0, y 20).
- The bench `[temperature_sensor hotend]` on the Octopus (PF4) reads about -51 °C: nothing is plugged in. It's stale and can go.
- Octopus firmware is v0.13.0-533 and the host is -642. It works; reflash the Octopus from the same tree when convenient.

## Function checks (2026-09-26)

- Part fan (M106 S102): the top fan spins and the bottom (hotend) fan doesn't, so FAN2 = part fan is correct.
- Stealthburner LEDs: not fitted; config section commented out.
- Filamatrix sensor on PB6: flips from not detected to detected when filament is inserted. Pin and polarity correct.
- **Known quirk: "Failed automated reset of MCU 'eddy'".** It happens whenever a config change forces the boards to reset (seen twice).
  The log shows the Eddy's clock carrying on, so it never executed the `reset` command. Klipper sends `reset`, pauses 15 ms and
  disconnects (`mcu.py _restart_via_command`), so there's no time for a host retransmit. The Eddy's software CAN (can2040 on the
  RP2040) can miss a frame that another node ACKs. **Workaround: run FIRMWARE_RESTART again; it has worked every time.**

## Calibration results

### Gantry rough level (2026-09-26)
Nozzle-to-bed with a ruler: X30 about 28 mm, X390 about 30 mm. `FORCE_MOVE STEPPER=stepper_z DISTANCE=2` (left up 2 mm), then both matched.
Z direction confirmed: positive = up, both motors together.

### Eddy offsets (2026-09-26)
The nozzle is centred side to side on the Eddy case. The case's square end is 16 mm behind the nozzle, and BTT's drawing puts the coil
centre 11.33 mm in from that end, so **x 0, y +27.33**. Y=0 is the front of the bed (the nozzle sits over the front edge at Y0), confirming +Y.
Case bottom is about 2.0 mm above the nozzle tip.

### Z_TILT (2026-09-26)
First attempt diverged (0.99 → 1.83 → 3.37, aborted) because **stepper_z is the RIGHT motor**, not the left as the bench config
labelled it. Proven with the Eddy: raising stepper_z 1 mm moved X390 +0.98 and X30 +0.17. The earlier rough level had therefore
raised the already-high side. The aborted adjustments were reversed with FORCE_MOVE, z_positions reordered (445 then -25), and the
labels fixed. Rerun: 0.982 → 0.021 → **0.0013 mm** in 3 rounds.

### eddy-ng setup (2026-09-26, bed cold, ~27 °C)
`PROBE_EDDY_NG_SETUP` at X210 Y210 with a paper test:
`Drive current 15: valid height: 0.000 to 15.000, freq spread 2.34% (3198802.6 - 3273722.6), Fit 0.0104` → reg/tap drive current 15.
First `G28 Z` via the Eddy was OK. `PROBE_EDDY_NG_PROBE_STATIC`: Z2 → 2.008 (±0.007, 3×), Z1 → 1.019, Z3 → 2.919. Saved with SAVE_CONFIG.
Redo warm (bed ~55 °C) once `[heater_bed]` is configured.

### PID (2026-09-26)
Hotend: `PID_CALIBRATE HEATER=extruder TARGET=250` → Kp 38.020 Ki 12.673 Kd 28.515 (reached 200 °C in about 25 s).
The hotend fan was found jammed (grinding) during this run and fixed; confirmed spinning at 60 °C.
Bed: `PID_CALIBRATE HEATER=heater_bed TARGET=60` → Kp 71.440 Ki 0.776 Kd 1644.914 (about 2 °C per 10 s at full power, DC MOSFET on HE0).

### eddy-ng setup, warm (bed 55 °C, Eddy NTC 44 °C) (2026-09-26)
Drive current 15, valid 0.001–15.000, spread 2.22%, fit 0.0105 (very close to cold). Static at Z2 → 2.004.
Tap 0.038/0.035/0.035 → **0.036, stddev 0.001**. Saved with SAVE_CONFIG (replaces the cold calibration).

### First mesh (bed 55 °C, after Z_TILT 0.291 → 0.014, tap stddev 0.017) (2026-09-26)
`BED_MESH_CALIBRATE METHOD=rapid_scan`, 21×21, saved as `default`. **Range 0.911 mm** (min -0.501, max +0.410).
Corners: FL +0.341, FR -0.454, BL +0.295, BR -0.152, centre -0.004. Middle row +0.28 … 0 … +0.30 (gantry bow / dish).
The front row falls from +0.34 on the left to -0.45 on the right, a left-right twist mostly at the front, which the gantry can't correct.
Tramming the bed with its corner screws should remove most of it.

### Bed tram, round 1 (cold, after Z_TILT) (2026-09-26)
SCREWS_TILT_CALCULATE (6 outer screws, LF reference), repeated twice with near-identical results:
LM CW 00:12, LB CW 00:13, RB CW 00:57, RM CW 00:06, RF CW 01:21 (RF 0.67 mm low vs LF).
Klipper CW-M3: CW = less gap = raises that corner.

### Silicone spacers, new Y motor, bed flattening (2026-09-27)
- **Y motor** replaced with an iMetrx 42x60 NEMA17 (2.1 A, 1.8°). The first move buzzed (coil pairs crossed), fixed by re-pinning.
  Now 1.2 A, SpreadCycle; +Y moves the bed forward (correct); homes fine.
- **homing_override bug:** a bare `SET_KINEMATIC_POSITION CLEAR_HOMED=z` marked X/Y homed (SET_HOMED defaults to xyz). Fixed.
- **Bed:** springs replaced by 18 mm silicone spacers on the **6 edge screws**. There is no centre screw. Two **centre standoffs**
  also bolt the bed to the carriage.
  - First mesh at 55 °C: nozzle dragged on the bed and the scan data went wild (a "no samples" failure). Z6 grid showed a **~2 mm bowl**.
    Cause: the two centre standoff screws were cranked down and pulled the middle of the plate toward the carriage.
    Loosened to half a turn from loose.
  - The Eddy is only accurate to about 3 mm (docs: up to 5 "mostly"). Spot checks at Z6 were misleading and caused one wasted FL round-trip (net 0 turns).
  - All six edge screws 2 turns CCW → mesh 1.65 → 1.23. Then corners only CCW (BL 1½, FL 1, BR 1, FR ½) → **0.715 mm**.
  - What's left is the same left-right U in every row (+0.5–0.65 at X15/X405): **gantry bow**, not the bed.
- **Pi 3 limit:** a 21x21 rapid scan plus eddy-ng `debug: True` (the default) stalled klippy → `MCU 'mcu' shutdown: Timer too close`.
  Fixed with `debug: False` and a 15x15 mesh (no stall since). Scan height back to 2.0.

### Extruder (2026-09-27)
- First extrude shut the SB2209 driver down: `TMC 'extruder' reports error: ShortToSupply_A OpenLoad_B`. Cause: split coil pairs
  in the E0 plug (coils on pins 1–3 and 2–4; this motor's pairs are blue+red and orange+black, not the wires that exit together).
  Swapped pins 2 and 3; the driver survived (clean DRV_STATUS afterwards).
- Direction correct (feeds down). About 60 mm to prime the empty CW2 → X1C path.
- E-steps check at 215 °C, PLA: 100 mm requested, **100 mm fed exactly** (120 mm mark → 20 mm left). rotation_distance 22.6789511, gear_ratio 50:10 unchanged.
- Filamatrix sensor detects loaded filament.

### First tap (2026-09-26, cold nozzle, clean, no filament)
`PROBE_EDDY_NG_TAP` at the bed centre: taps -0.113 / -0.100 / -0.105 → **-0.106, stddev 0.005**, overshoot 0.035, sensor offset 0.105 at z=2.
The contact point was about 0.1 mm (one paper thickness) below the paper-test zero, as expected.
Paper check after the tap: Z0.3 free, Z0.2 slight drag, Z0.1 more drag, Z0 drag (eddy-ng's target is "a good amount of friction" at Z0).
`tap_adjust_z` left at 0 until a first-layer print says otherwise.

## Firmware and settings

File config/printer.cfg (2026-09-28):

[include hardware/sb2209.cfg]
[include hardware/eddy.cfg]
[include hardware/bed_mesh.cfg]
[include hardware/eddy_homing.cfg]
[include hardware/z_tilt.cfg]
[include hardware/screws_tilt.cfg]
[include mainsail.cfg]
[include KAMP_Settings.cfg]
[include macros/print.cfg]

[mcu]
serial: /dev/serial/by-id/usb-Klipper_stm32f446xx_330034000951343437373238-if00

[printer]
kinematics: cartesian
max_velocity: 200
max_accel: 2000
max_z_velocity: 10
max_z_accel: 100

[force_move]
enable_force_move: True

# ---------- MOTOR0: X ----------
[stepper_x]
step_pin: PF13
dir_pin: !PF12
enable_pin: !PF14
microsteps: 16
rotation_distance: 40
endstop_pin: ^PG6
position_endstop: 0
position_max: 420
homing_speed: 30

[tmc2209 stepper_x]
uart_pin: PC4
run_current: 0.800
stealthchop_threshold: 999999

# ---------- MOTOR1: Y ----------
[stepper_y]
step_pin: PG0
dir_pin: !PG1
enable_pin: !PF15
microsteps: 16
rotation_distance: 40
endstop_pin: ^PG9
position_endstop: 0
position_max: 420
homing_speed: 30

[tmc2209 stepper_y]
uart_pin: PD11
run_current: 1.2            # iMetrx 42x60 NEMA17, 2.1 A rated, 1.8° (fitted 2026-09-27); max ~1.4-1.5
stealthchop_threshold: 0     # SpreadCycle: more torque for the heavy bed

# ---------- MOTOR3: Z right (verified 2026-09-26) ----------
[stepper_z]
step_pin: PG4
dir_pin: PC1
enable_pin: !PA0
microsteps: 16
rotation_distance: 8
endstop_pin: probe:z_virtual_endstop   # Eddy (eddy-ng); stock Z switch on PG11 retired 2026-09-26
position_min: -2                       # eddy-ng tap presses slightly below Z=0
position_max: 500
homing_retract_dist: 0

[tmc2209 stepper_z]
uart_pin: PC7
run_current: 0.600
stealthchop_threshold: 999999

# ---------- MOTOR4: Z left (verified 2026-09-26) ----------
[stepper_z1]
step_pin: PF9
dir_pin: PF10
enable_pin: !PG2
microsteps: 16
rotation_distance: 8

[tmc2209 stepper_z1]
uart_pin: PF2
run_current: 0.600
stealthchop_threshold: 999999

# ---------- sensors ----------
# Bed: Octopus HE0 (PA2) drives an external MOSFET module that switches the bed (user, 2026-09-26).
# HE0 = PA2 per klipper/config/generic-bigtreetech-octopus-v1.1.cfg. Thermistor on TB (PF3).
[heater_bed]
heater_pin: PA2
sensor_type: Generic 3950
sensor_pin: PF3
min_temp: 0
max_temp: 110
control: pid                # PID_CALIBRATE HEATER=heater_bed TARGET=60, 2026-09-26
pid_Kp: 71.440
pid_Ki: 0.776
pid_Kd: 1644.914

# Stock Elegoo runout sensor: still wired, but not mounted yet (2026-09-26).
# Keep pause_on_runout off and don't reference it from any macro.
[filament_switch_sensor filament]
switch_pin: ^PG10
pause_on_runout: False

# ---------- fans / light ----------
[led caselight]
white_pin: PA8
initial_white: 1.0

[fan_generic case_fan]
pin: PE5

[fan_generic hotend_fan]
pin: PD12

# ---------- misc ----------
[exclude_object]                 # needed by KAMP and for cancelling single objects in Mainsail

[virtual_sdcard]
path: ~/printer_data/gcodes
[pause_resume]
[display_status]
[respond]

#*# <---------------------- SAVE_CONFIG ---------------------->
#*# DO NOT EDIT THIS BLOCK OR BELOW. The contents are auto-generated.
#*#
#*# [probe_eddy_ng btt_eddy]
#*# calibrated_drive_currents = 15
#*# calibration_version = 5
#*# reg_drive_current = 15
#*# tap_drive_current = 15
#*# calibration_15 = gASVywMAAAAAAAB9lCiMAXaUSwWMBGZ0b2iUjBtudW1weS5wb2x5bm9taWFsLnBvbHlub21pYWyUjApQb2x5bm9taWFslJOUKYGUfZQojARjb2VmlIwWbnVtcHkuX2NvcmUubXVsdGlhcnJheZSMDF9yZWNvbnN0cnVjdJSTlIwFbnVtcHmUjAduZGFycmF5lJOUSwCFlEMBYpSHlFKUKEsBSwqFlGgMjAVkdHlwZZSTlIwCZjiUiYiHlFKUKEsDjAE8lE5OTkr/////Sv////9LAHSUYolDUHD+V2px2fQ/q5kWwqBk/D83zA87IL7qP5dahh5ka+A/Bn96YyG/sT+QqpxIihnDPztI87XhdNc/GLMdxYblyb8XsEAI9EGrv9OnrqmL0dE/lHSUYowGZG9tYWlulGgLaA5LAIWUaBCHlFKUKEsBSwKFlGgYiUMQ1yA+g7aFlD5k5MdMFemUPpR0lGKMBndpbmRvd5RoC2gOSwCFlGgQh5RSlChLAUsChZRoGIlDEAAAAAAAAPC/AAAAAAAA8D+UdJRijAdfc3ltYm9slIwBeJSMBnN5bWJvbJRoLHVijAlmdG9oX2hpZ2iUaAUpgZR9lChoCGgLaA5LAIWUaBCHlFKUKEsBSwqFlGgYiUNQHFqKkqCoGkA8u150aLwJQPiiVQk3SPg/2C8eefFe8D8FimETC0IBQJt5R8hRdfc/NyAU+zNPBMBB5mm5AVz8v0qQzSReCAFA/P/Jp2nQ9z+UdJRiaB1oC2gOSwCFlGgQh5RSlChLAUsChZRoGIlDEFrYEk+x5ZQ+6fbvEjL6lD6UdJRiaCRoC2gOSwCFlGgQh5RSlChLAUsChZRoGIlDEAAAAAAAAPC/AAAAAAAA8D+UdJRiaCtoLGgtaCx1YowEaHRvZpRoBSmBlH2UKGgIaAtoDksAhZRoEIeUUpQoSwFLCoWUaBiJQ1BmPaU2ntCUPjmGLk4OdCM+IaVIsLd1Fr4K2dLQueIOPh/J9x0TItG9L6s3KFonE74Wi30xkEX9vYPMLX/j3B0+0xGNuUzZ9D27UfKE3n8OvpR0lGJoHWgLaA5LAIWUaBCHlFKUKEsBSwKFlGgYiUMQALpIUIizSj8A75SK1/0TQJR0lGJoJGgLaA5LAIWUaBCHlFKUKEsBSwKFlGgYiUMQAAAAAAAA8L8AAAAAAADwP5R0lGJoK2gsaC1oLHVijAdoX3JhbmdllF2UKEc/SrOIUEi6AEdALf/7aiDIUmWMB2ZfcmFuZ2WUXZQoR0FIaEUd21AAR0FI8s2vwgAAZYwCZGOUSw91Lg==
#*#
#*# [bed_mesh default]
#*# version = 1
#*# points =
#*# 	  0.340834, 0.242057, 0.184771, 0.151342, 0.069173, 0.004384, 0.028100, 0.052728, -0.017402, -0.068440, -0.088686, -0.136606, -0.179748, -0.190807, -0.221536, -0.412367, -0.416678, -0.426637, -0.475932, -0.500899, -0.453999
#*# 	  0.410007, 0.315921, 0.256174, 0.232471, 0.162612, 0.093696, 0.054474, 0.033208, -0.031714, -0.081435, -0.094095, -0.133408, -0.180596, -0.181688, -0.191663, -0.254473, -0.261013, -0.263019, -0.283386, -0.318240, -0.300041
#*# 	  0.393021, 0.281496, 0.231226, 0.207774, 0.127504, 0.065507, 0.039477, 0.018835, -0.054066, -0.094095, -0.109994, -0.146609, -0.182541, -0.192569, -0.196051, -0.243520, -0.266419, -0.248208, -0.288160, -0.287714, -0.257863
#*# 	  0.367274, 0.264776, 0.208138, 0.182219, 0.119622, 0.060095, 0.036741, 0.022592, -0.048761, -0.083291, -0.097645, -0.132343, -0.171282, -0.177329, -0.171943, -0.218884, -0.226614, -0.218451, -0.236604, -0.256288, -0.224628
#*# 	  0.370429, 0.246130, 0.192584, 0.178203, 0.112463, 0.064541, 0.042601, 0.031050, -0.047964, -0.067817, -0.081044, -0.114406, -0.144887, -0.140416, -0.138091, -0.183631, -0.179506, -0.166758, -0.180594, -0.180173, -0.135957
#*# 	  0.325962, 0.224805, 0.167392, 0.154678, 0.097689, 0.038887, 0.026331, 0.016661, -0.048356, -0.069254, -0.062472, -0.089099, -0.123488, -0.107472, -0.093684, -0.134472, -0.119457, -0.097233, -0.109159, -0.104954, -0.036577
#*# 	  0.320476, 0.202715, 0.162238, 0.148198, 0.090073, 0.039477, 0.025943, 0.029085, -0.037381, -0.037592, -0.044295, -0.059616, -0.079358, -0.060013, -0.030911, -0.073582, -0.053257, -0.023030, -0.020614, 0.004776, 0.076671
#*# 	  0.296381, 0.207052, 0.166106, 0.155600, 0.102627, 0.051367, 0.037522, 0.043380, -0.007376, -0.007983, -0.001585, -0.016793, -0.033529, -0.010575, 0.028691, -0.009175, 0.027508, 0.068202, 0.085105, 0.106036, 0.189860
#*# 	  0.305981, 0.203986, 0.160580, 0.158737, 0.096359, 0.053108, 0.048644, 0.055057, 0.004983, -0.004187, 0.001994, -0.014782, -0.019607, 0.013516, 0.046693, 0.018451, 0.052726, 0.102437, 0.123568, 0.164081, 0.244361
#*# 	  0.260387, 0.173448, 0.148941, 0.129003, 0.090453, 0.038300, 0.040646, 0.037708, -0.004583, -0.013987, 0.000602, -0.001398, -0.013194, 0.010145, 0.050592, 0.032811, 0.066857, 0.127131, 0.153381, 0.179850, 0.272796
#*# 	  0.280466, 0.176008, 0.144670, 0.142068, 0.079936, 0.045915, 0.036535, 0.030068, -0.011391, -0.014384, -0.004196, -0.017801, -0.019208, 0.012318, 0.045331, 0.024565, 0.074176, 0.123943, 0.162600, 0.212090, 0.297058
#*# 	  0.238334, 0.160029, 0.127131, 0.121312, 0.071868, 0.024566, 0.011926, 0.021811, -0.027873, -0.024653, -0.010783, -0.012587, -0.032730, -0.001396, 0.041624, 0.017462, 0.057959, 0.119435, 0.150422, 0.194220, 0.287568
#*# 	  0.242770, 0.138342, 0.121314, 0.113219, 0.065891, 0.014899, 0.009545, 0.012318, -0.039818, -0.041237, -0.032516, -0.041237, -0.035962, -0.017002, 0.011925, -0.007584, 0.033798, 0.093124, 0.117741, 0.157446, 0.244179
#*# 	  0.210472, 0.127507, 0.106601, 0.096546, 0.048445, 0.010536, -0.004187, 0.006375, -0.035962, -0.043463, -0.011578, -0.029284, -0.045101, -0.023035, 0.010334, -0.009785, 0.021811, 0.083958, 0.097310, 0.123378, 0.217118
#*# 	  0.209551, 0.109817, 0.089499, 0.086060, 0.043380, 0.008552, 0.008948, 0.009546, -0.042659, -0.035353, -0.026060, -0.035753, -0.050400, -0.041641, -0.004586, -0.026461, 0.001204, 0.046896, 0.060867, 0.088162, 0.157448
#*# 	  0.163521, 0.099021, 0.071860, 0.068587, 0.031639, -0.011582, -0.020830, -0.004187, -0.044083, -0.051829, -0.038005, -0.042042, -0.068031, -0.052854, -0.025661, -0.059607, -0.035970, -0.001585, 0.001991, 0.007162, 0.080510
#*# 	  0.214604, 0.119998, 0.095980, 0.101868, 0.055831, 0.023180, 0.016473, 0.020821, -0.028678, -0.022422, -0.020215, -0.028676, -0.056118, -0.042661, -0.022426, -0.062879, -0.038799, -0.005583, -0.024438, -0.016394, 0.050780
#*# 	  0.214782, 0.150792, 0.127880, 0.125819, 0.090831, 0.045331, 0.050006, 0.048644, 0.001995, -0.002795, 0.001599, -0.010575, -0.033133, -0.035347, -0.013589, -0.062473, -0.053257, -0.031312, -0.050400, -0.057549, 0.002992
#*# 	  0.221397, 0.160582, 0.138716, 0.142435, 0.091790, 0.056415, 0.055444, 0.057380, 0.005774, 0.008157, 0.000602, -0.022021, -0.041237, -0.036364, -0.015996, -0.073170, -0.068222, -0.049378, -0.075023, -0.085790, -0.056118
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

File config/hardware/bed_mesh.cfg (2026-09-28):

# Bed mesh for the 420 x 420 bed, scanned by the Eddy (eddy-ng).
# mesh_min/mesh_max follow BTT's formula for the measured offsets in eddy.cfg (x 0, y +27.33):
#   min = 0   + max(15, offset if positive)      max = 420 - max(15, |offset| if negative)
[bed_mesh]
horizontal_move_z: 2.0     # eddy-ng's most accurate scan height (bed trammed flat 2026-09-27; min clearance ~1.3 mm)
speed: 150
mesh_min: 15, 28
mesh_max: 405, 405
probe_count: 15, 15        # 21x21 stalled the Pi 3 host (Timer too close); 28 mm spacing is plenty
algorithm: bicubic
adaptive_margin: 5         # extra mm around the print area for ADAPTIVE=1 meshes

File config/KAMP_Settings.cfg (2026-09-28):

# KAMP settings for the Neptune 3 Max. Upstream: github.com/kyleisah/Klipper-Adaptive-Meshing-Purging (997838c).
# ~/printer_data/config/KAMP is a symlink to ~/Klipper-Adaptive-Meshing-Purging/Configuration on the Pi.
# Only LINE_PURGE and SMART_PARK are used; tip_distance 1 matches PRINT_END's 1 mm retract.

# Below you can include specific configuration files depending on what you want KAMP to do:

#[include ./KAMP/Adaptive_Meshing.cfg]       # Not used: PRINT_START calls Klipper's native BED_MESH_CALIBRATE ADAPTIVE=1 (eddy-ng rapid_scan).
[include ./KAMP/Line_Purge.cfg]             # Include to enable adaptive line purging configuration.
#[include ./KAMP/Voron_Purge.cfg]            # Include to enable adaptive Voron logo purging configuration.
[include ./KAMP/Smart_Park.cfg]             # Include to enable the Smart Park function, which parks the printhead near the print area for final heating.

[gcode_macro _KAMP_Settings]
description: This macro contains all adjustable settings for KAMP 

# The following variables are settings for KAMP as a whole.
variable_verbose_enable: True               # Set to True to enable KAMP information output when running. This is useful for debugging.

# The following variables are for adjusting adaptive mesh settings for KAMP.
variable_mesh_margin: 0                     # Expands the mesh size in millimeters if desired. Leave at 0 to disable.
variable_fuzz_amount: 0                     # Slightly randomizes mesh points to spread out wear from nozzle-based probes. Leave at 0 to disable.

# The following variables are for those with a dockable probe like Klicky, Euclid, etc.                 # ----------------  Attach Macro | Detach Macro
variable_probe_dock_enable: False           # Set to True to enable the usage of a dockable probe.      # ---------------------------------------------
variable_attach_macro: 'Attach_Probe'       # The macro that is used to attach the probe.               # Klicky Probe:   'Attach_Probe' | 'Dock_Probe'
variable_detach_macro: 'Dock_Probe'         # The macro that is used to store the probe.                # Euclid Probe:   'Deploy_Probe' | 'Stow_Probe'
                                                                                                        # Legacy Gcode:   'M401'         | 'M402'

# The following variables are for adjusting adaptive purge settings for KAMP.
variable_purge_height: 0.8                  # Z position of nozzle during purge, default is 0.8 mm.
variable_tip_distance: 1                    # Distance in mm between tip of filament and nozzle before purge. Should be similar to PRINT_END final retract amount.
variable_purge_margin: 10                   # Distance the purge will be in front of the print area, default is 10 mm.
variable_purge_amount: 30                   # Amount of filament in mm to be purged prior to printing.
variable_flow_rate: 12                      # Flow rate of purge in mm3/s. Default is 12.

# The following variables are for adjusting the Smart Park feature for KAMP, which will park the printhead near the print area at a specified height.
variable_smart_park_height: 10              # Z position for Smart Park, default is 10 mm.

gcode: # Gcode section left intentionally blank. Do not disturb.

    {action_respond_info(" Running the KAMP_Settings macro does nothing, it is only used for storing KAMP settings. ")}

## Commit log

2026-09-20 Add build README for the Neptune 3 Max Klipper conversion
    Documents the full teardown-and-rebuild plan: Octopus v1.1 with USB-to-CAN
    bridge, SB2209 toolhead, Stealthburner + CW2 with an X1C hotend, independent
    dual Z with z_tilt, and a scanning probe still to be chosen.
    Includes the stock-vs-target subsystem table, a BOM marked up for what's in
    hand, a six-phase build checklist, open decisions, and safety notes covering
    the X1C heater / SB2209 output check and PSU headroom.
2026-09-20 Add toolhead STLs sorted by print colour
    Stealthburner + Clockwork 2 (FilamATrix fork) for the X1C hotend, reorganised
    from the upstream source-based layout into primary/accent/clear/opaque folders
    so each can be imported and printed as a single batch.
    Choose-one variants resolved for this build: single-switch CW2 main body with
    the matching sensor cable cover, standard razor blade, Filametrix cutter kept,
    no cable chain anchors. The unused variants are parked in alternates/ with the
    reasoning recorded rather than deleted.
    Every part is quantity 1 — no file in this set carries Voron's _x# multiplicity
    suffix, upstream or here.
    [[a]_cutting_arm_clockwork2.stl, [a]_guidler_a.stl, [a]_guidler_b.stl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]
2026-09-20 Add bench bring-up printer.cfg for the Octopus v1.1
    First working config: X/Y/Z/Z1 steppers on MOTOR0/1/3/4 with TMC2209 UART,
    endstops, thermistors as read-only sensors, fans and case light.
    Motion and sensing only — no heaters, no CAN toolhead, no probe yet. This is
    the Phase 2 bench config, not a printable one.
    [printer.cfg]
2026-09-26 Add CAN bring-up plan, firmware configs, and draft SB2209/Eddy configs
    Switch the CAN adapter to a BTT U2C v2.1; the Octopus stays plain USB Klipper.
    Firmware .configs generated with make olddefconfig (Klipper ce7002b,
    Katapult ec59b9b). Sources for each value:
    - Octopus v1.1 STM32F446ZET6: 32KiB bootloader, 12 MHz crystal, USB
    PA11/PA12 (Esoterical guide, Octopus F446 page; chip and crystal read
    off the board)
    - SB2209 STM32G0B1: 8KiB bootloader, 8 MHz crystal, CAN PB0/PB1, 1M
    (Esoterical guide SB2209/SB2240 page; BTT SB2209 V1.0 schematic)
    - Eddy Duo RP2040: 16KiB bootloader, CAN RX gpio4 / TX gpio5, 1M
    (Esoterical guide Eddy Duo page; RP2040 Katapult launch address is
    fixed at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
    [eddy.cfg, sb2209.cfg]
2026-09-26 Record fan mapping, Filamatrix sensor wiring and Eddy-as-Z-endstop decision
    [eddy.cfg, sb2209.cfg]
2026-09-26 Switch Eddy config to eddy-ng; record eddy-ng install on the Pi
    [eddy.cfg]
2026-09-27 Termination: Eddy Duo terminates the far end, SB2209 120R off (41 -> 60 ohm)
2026-09-27 CAN bus live: SB2209 and Eddy flashed over CAN, configs included
    Octopus + SB2209 (e0ee669c3821) + Eddy Duo (6e4e53261cb4) all ready in Klipper.
    Eddy homing split into eddy_homing.cfg (not included until calibrated).
    Probe offsets and bed_mesh are placeholders until measured.
    [bed_mesh.cfg, eddy.cfg, eddy_homing.cfg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]
2026-09-27 Comment out Stealthburner LEDs (not fitted); part fan on FAN2 verified
    [sb2209.cfg]
2026-09-27 Function checks: part fan, Filamatrix sensor verified
    [sb2209.cfg]
2026-09-27 Remove stale bench hotend sensor; keep Elegoo runout sensor unused
    [printer.cfg]
2026-09-27 Eddy offsets measured: x 0, y +27.33; mesh bounds updated
    [bed_mesh.cfg, eddy.cfg]
2026-09-27 Z endstop -> Eddy virtual endstop; include eddy_homing.cfg; position_min -2
    [eddy_homing.cfg, printer.cfg]
2026-09-27 homing_override: don't leave Z falsely homed after the pre-home lift
    [eddy_homing.cfg]
2026-09-27 eddy-ng setup saved (drive current 15, 0-15 mm valid); first Eddy Z home OK
    [printer.cfg]
2026-09-27 Add z_tilt (screws at X-25/445) and heater_bed on HE0/PA2
    [printer.cfg, z_tilt.cfg]
2026-09-27 Fix Z motor sides (stepper_z = right); z_tilt converges to 0.0013 mm
    [printer.cfg, z_tilt.cfg]
2026-09-27 Hotend PID (Kp 38.020 Ki 12.673 Kd 28.515); hotend fan found jammed
    [sb2209.cfg]
2026-09-27 Bed PID (Kp 71.440 Ki 0.776 Kd 1644.914)
    [printer.cfg]
2026-09-27 Warm eddy-ng calibration, first 21x21 mesh (range 0.911), PIDs recorded
    [printer.cfg]
2026-09-27 Add screws_tilt_adjust (6 outer M3 screws, centre excluded)
    [printer.cfg, screws_tilt.cfg]
2026-09-27 Screw positions confirmed; record tram round 1
    [screws_tilt.cfg]
2026-09-27 README: bring status, BOM, phases and decisions up to date with the verified bring-up
2026-09-27 Y: new 42x60 motor, 1.2 A, SpreadCycle
    [printer.cfg]
2026-09-27 homing_override: SET_HOMED=z with CLEAR_HOMED=z so X/Y aren't falsely homed
    [eddy_homing.cfg]
2026-09-27 screws_tilt: bed has 6 edge screws, no centre screw
    [screws_tilt.cfg]
2026-09-27 bed_mesh: scan at 3 mm until the bed is flatter
    [bed_mesh.cfg]
2026-09-28 eddy-ng debug off, mesh 15x15: avoid Timer too close on the Pi 3
    [bed_mesh.cfg, eddy.cfg]
2026-09-28 Bed trammed on silicone spacers: mesh 0.715 mm (gantry bow only); scan height back to 2 mm
    [bed_mesh.cfg]
2026-09-28 Extruder verified: direction OK, 100 mm = 100 mm; E0 plug re-pinned
    [sb2209.cfg]
2026-09-28 PRINT_START/PRINT_END macros, KAMP (line purge + smart park), exclude_object, mainsail.cfg
    [KAMP_Settings.cfg, bed_mesh.cfg, print.cfg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]
2026-09-28 OrcaSlicer printer preset: Neptune 3 Max 0.4 (inherits MyKlipper 0.4 nozzle)
2026-09-28 README: photos (printer, toolhead, electronics) and first-print clip; status update
    Media re-encoded with all metadata (including GPS) stripped.
